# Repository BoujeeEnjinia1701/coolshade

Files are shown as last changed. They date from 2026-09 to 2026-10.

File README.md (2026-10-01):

# CoolShade

     

**Area:** Smart Cities · **TRL:** 3 of 9 (proof of concept on paper) · **Value-engineering target:** about $775 USD (hypothetical control target; estimated parts cost $882, $107 over) · **Difficulty:** 3 of 5

A solar-powered shade canopy with fine misting for bus stops, markets and queues, switching on only when heat stress is high.

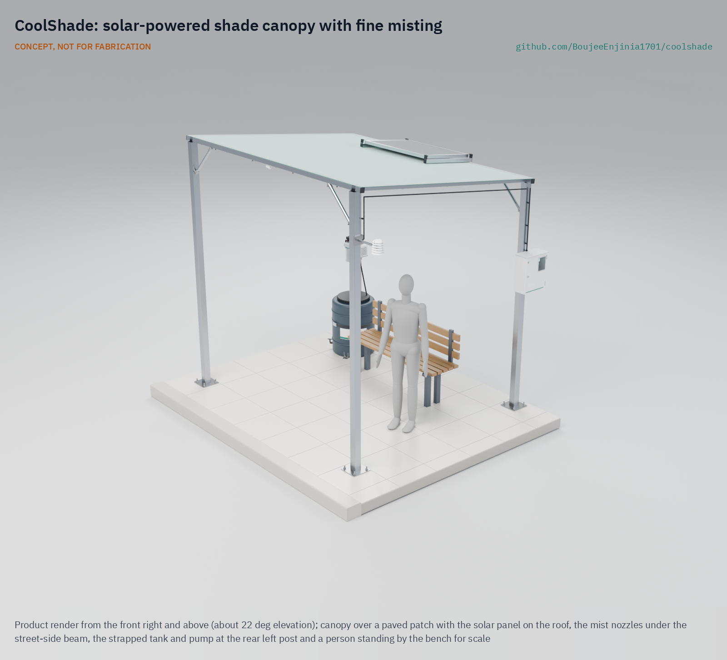
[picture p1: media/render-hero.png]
CoolShade: solar-powered shade canopy with fine misting, product render


[Prototype build plan](docs/05-build-plan.md) · [Design decisions](docs/06-design-decisions.md) · [Exploded render](media/render-exploded.png) · [Detail render](media/render-detail.png) · [Interactive 3D model](media/viewer.html) · [Concept blueprint (PDF)](media/concept-blueprint.pdf) · [General arrangement (PDF)](cad/drawings/CSH-DWG-001.pdf) · [Sizing calculations](docs/04-calcs/01-sizing.md) · [Review note](docs/REVIEW.md)

## Concept rationale

For a person waiting in the sun, radiant heat from the sun and hot pavement matters as much as air temperature, and shade removes most of it: in Tempe, Arizona, even shade sails cut the daytime mean radiant temperature by about 17 °C ([Middel et al., 2021](https://journals.ametsoc.org/view/journals/bams/102/9/BAMS-D-20-0193.1.xml)). CoolShade therefore starts with shade and adds low-pressure misting only when it helps: when the air is hot and dry enough for evaporation to cool it and someone is actually waiting. Gating on humidity and presence keeps water and energy use low (85 L and about 204 Wh on a hot, dry day, from the TRL 3 calculations) and avoids wetting people in humid air.

It is open and garage-buildable because the places that need it most, curbside stops, informal markets and distribution queues, rarely have power, budgets or staff for commercial misting systems. The frame is bolted steel tube, the roof is shade cloth, and the power and water parts are generic 12 V solar, pump and irrigation parts. Cities, schools and community groups can build, move, repair and audit it, including the water hygiene plan that any public misting system needs.

## Burning platform

WHO estimates about 489,000 heat-related deaths each year between 2000 and 2019, 45 % of them in Asia and 36 % in Europe, and notes that informal settlements are often hotter than other urban areas ([WHO](https://www.who.int/news-room/fact-sheets/detail/climate-change-heat-and-health)). In one summer, 2022, an estimated 61,672 people died of heat across 35 European countries ([Ballester et al., *Nature Medicine*, 2023](https://www.nature.com/articles/s41591-023-02419-z)).

Heat also takes work time from people who spend their day outdoors: the ILO projects that 2.2 % of total working hours worldwide will be lost to higher temperatures by 2030, equivalent to 80 million full-time jobs ([ILO, 2019](https://www.ilo.org/global/about-the-ilo/newsroom/news/WCMS_711917/lang--en/index.htm)). Cooling centers help people who can reach them, but many people are exposed where they must wait: at bus stops, in market lanes and in queues.

## Where it could be used

### By industry

| Industry | Use |
| --- | --- |
| Public transit | Shade and misting at busy unsheltered bus and minibus stops, and at terminals with long waits |
| Municipal markets | Cooled waiting and trading spots in open-air and informal markets during the midday peak |
| Public health and humanitarian response | Relief at clinic, vaccination, food and water distribution queues and at camp service points |
| Education | Shade at school gates, playgrounds and pickup areas |
| Construction and outdoor work | Shaded, cooled rest points near sites, with water use logged |
| Events and tourism | Queues at venues, heritage sites and festivals in hot seasons |

### By country or region

| Country or region | Why it matters there |
| --- | --- |
| United States | In all but 6 of the 175 largest urbanized areas, the average person of color lives in a census tract with higher surface urban heat island intensity than non-Hispanic white residents ([Hsu et al., 2021](https://www.nature.com/articles/s41467-021-22799-5)); transit riders in these areas wait in the heat |
| Europe | About 61,672 heat-related deaths in summer 2022 across 35 countries ([Ballester et al., 2023](https://www.nature.com/articles/s41591-023-02419-z)); shade for waiting places in dense cities has to be added without new buildings |
| India | An assessment of 37 city, district and state heat action plans found that vulnerable groups are rarely identified or targeted ([CPR, 2023](https://cprindia.org/briefsreports/how-is-india-adapting-to-heatwaves-an-assessment-of-heat-action-plans-with-insights-for-transformative-climate-action/)); low-cost shade at markets and stops is a practical measure such plans can fund |
| Sub-Saharan Africa | Africa warmed by about 0.3 °C per decade over 1991 to 2022 ([WMO](https://wmo.int/news/media-centre/africa-suffers-disproportionately-from-climate-change)); open-air markets and minibus ranks are central to daily life and shade, power and piped water cannot be assumed there |
| North Africa and the Middle East | WMO reports warming has been most intense in North Africa, with extreme heat in 2022 ([WMO](https://wmo.int/news/media-centre/africa-suffers-disproportionately-from-climate-change)); dry air there suits evaporative misting well |

## What sparked the idea

The idea traces back to Expo '92 in Seville, where the midday summer heat would have made the open public spaces unlivable without the site's designed microclimate. Its designers combined three measures: shading to block the sun, cold surfaces of vegetation and water, and cold air made by micronizing water in the passage areas where visitors walked and queued ([Castro Medina et al., *Sustainability*, 2022](https://doi.org/10.3390/su142114173)). That system served a showcase site with mains power, piped water and staff on hand. CoolShade takes the same order, shade first and mist second, and asks whether it can fit in a bolted canopy that runs from a panel and a tank at an ordinary bus stop or market lane, with the humidity and presence gating and the hygiene routine that an unattended public site needs.

## Problem

People waiting outdoors in extreme heat have nowhere to cool down, and public cooling is rarely where they wait. Full problem statement: [docs/01-problem.md](docs/01-problem.md).

## Concept

A four-post bolted steel canopy, 3.0 x 2.4 m, on a 2.8 x 2.35 m post grid, with a knitted shade cloth roof laced over the frame, a 100 W solar panel and a 12.8 V LiFePO4 battery. A 12 V diaphragm pump sends filtered water from a 120 L tank at about 7 bar to eight anti-drip nozzles under the roof beams. The controller mists only when the air is 32 °C or more, relative humidity is 60 % or less and a passive infrared sensor sees someone waiting; a normally open valve drains the line after every session. No camera or microphone is fitted.

TRL 3 calculations ([CSH-CAL-001](docs/04-calcs/01-sizing.md)): about 17 °C lower mean radiant temperature from the shade (from published shade sail measurements), 2.71 °C lower air temperature while spraying at 1 m/s wind (1.35 °C averaged over the spray cycle), 85 L of water and 204 Wh per hot, dry day, a 25 Ah battery lasting 1.26 days without sun, one tank lasting 1.41 days, headroom of 2,223 mm, and an estimated $882 in parts, $107 over the $775 value-engineering target (a hypothetical control target, not a limit) once every part needed to build it is counted. The frame and anchors are sized to survive a 30 m/s gust with the fabric removed; the fabric goes on only when forecast gusts are below 15 m/s (54 km/h), because its edge pull would overload the roof beams in a storm. Cost (R13) is over the value-engineering target by $107; savings worth trying are in the design decisions register. At risk: *Legionella* control in warm stored water and nozzle scaling; wetting cannot be judged until droplet data are in hand. Design decisions: [CSH-DDR-001](docs/decisions/0001-trl2-review-decisions.md), [CSH-DDR-002](docs/decisions/0002-recommendations-accepted.md) and [CSH-DDR-003](docs/decisions/0003-design-for-construction.md) (design for construction), indexed in the [design decisions register](docs/06-design-decisions.md).

Full design precis: [docs/02-concept.md](docs/02-concept.md). Requirements: [docs/03-requirements.md](docs/03-requirements.md).

## Key components

1. Posts, 80 x 80 mm galvanized steel, with knee braces
2. Roof frame, 50 x 50 mm steel, joined by angle cleats and rivet nuts
3. Shade fabric, knitted HDPE
4. Base plates, base cleats and anchors
5. Solar panel, 100 W, on rails at the roof's rear edge
6. LiFePO4 battery, 12.8 V 25 Ah
7. MPPT charge controller
8. Controller in a lockable IP65 enclosure
9. Sensor head: temperature and humidity in a radiation shield, PIR presence sensor
10. Misting pump, 12 V, about 7 bar, on an equipment plate
11. Filter, 5 µm, and check valve
12. Mist line loop with 8 anti-drip nozzles
13. Water tank, 120 L, opaque, strapped, with a low-level switch
14. Normally open drain valve and vacuum breaker
15. Hose and wiring harness

The priced bill of materials is in [bom/bom.csv](bom/bom.csv). The parametric model is [cad/src/model.py](cad/src/model.py), with STEP and STL exports in `cad/step/` and `cad/stl/`; `python cad/src/model.py --check` runs its constructability checks.

## Building the prototype

The prototype build plan ([docs/05-build-plan.md](docs/05-build-plan.md), CSH-BLD-001) shows, in pictures drawn from the model, how to make each of the canopy's steel parts and how to put the whole prototype together in 17 steps. Every joint is bolted: angle cleats join the tubes, bolts into the closed beams go into rivet nuts, and there is no welding. Making the design buildable changed some of the concept (posts moved out to carry the cloth's edges, the panel moved to the rear edge on its own bearer, and more); the changes are in [CSH-DDR-003](docs/decisions/0003-design-for-construction.md), and decisions still open are in the [design decisions register](docs/06-design-decisions.md). It is a plan, not yet built.

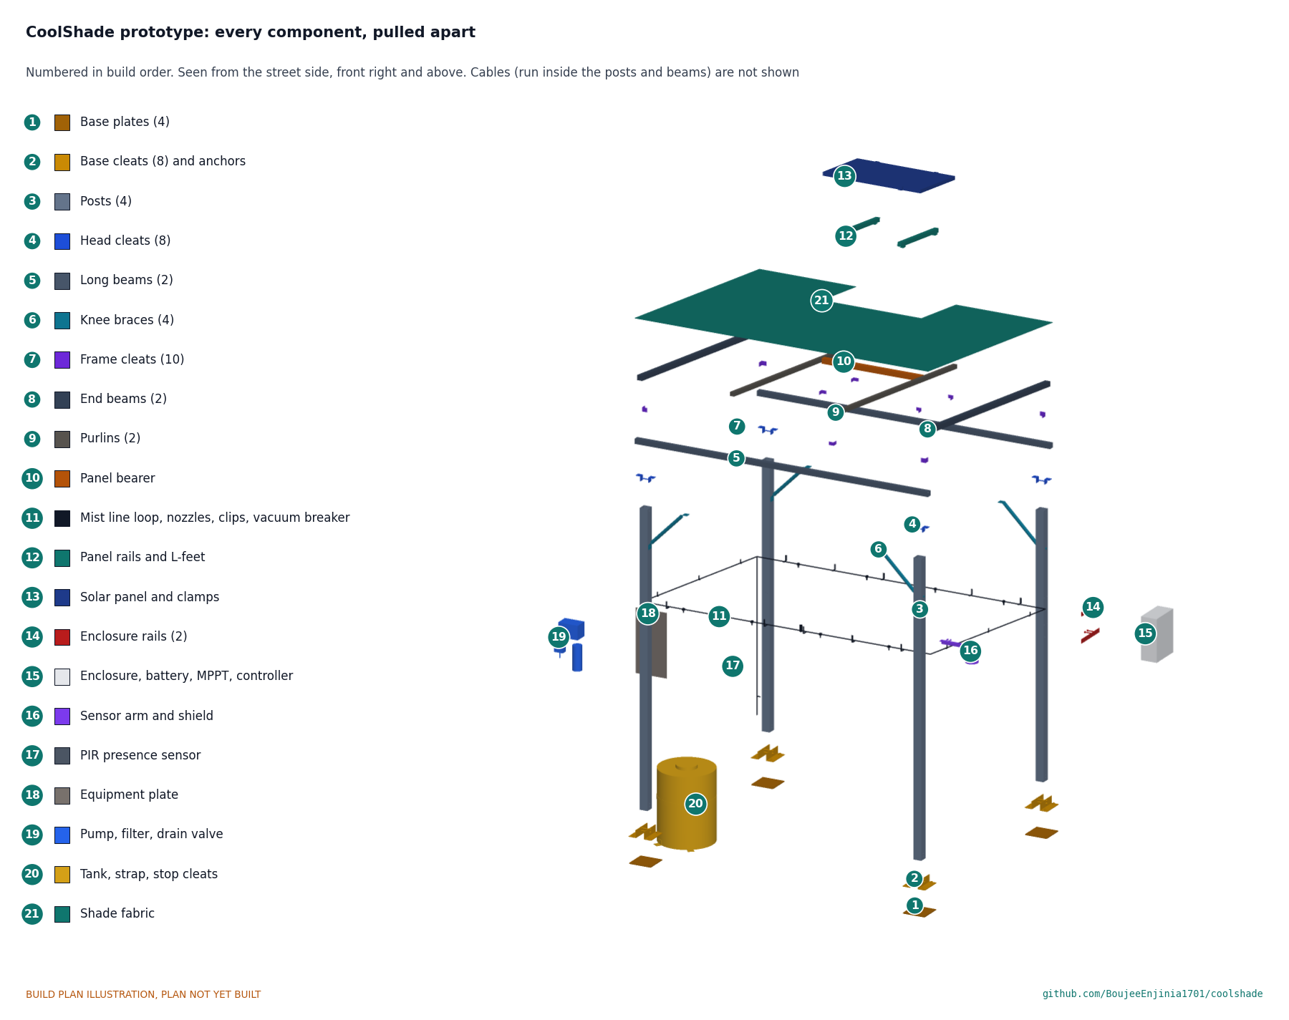
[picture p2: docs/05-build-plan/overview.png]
CoolShade prototype: every component, pulled apart and numbered in build order


## Safety

> Misting makes an aerosol. *Legionella* grows in water at 20 to 50 °C and infects people who breathe in contaminated mist ([WHO](https://www.who.int/news-room/fact-sheets/detail/legionellosis)). Use potable water only, keep the tank opaque and shaded, drain the line after every session, flush the tank daily and disinfect it weekly, and stop misting if the water is not maintained. Misting is ineffective in high humidity; the controller must switch off then.
>
> Lithium cells can overheat, vent and burn. Use protected cells or LiFePO4, fuse every pack, charge only within the cell maker's limits and never leave a first build charging unattended.
>
> The canopy is a wind-loaded structure: anchor it to a checked slab or footing, strap the tank, fit the fabric only when forecast gusts are below 15 m/s, and remove it before storms. Building it is work at height with heavy steel. The pump line runs at about 7 bar; depressurize it before opening fittings. Install on public land only with the asset owner's permission.

## Repository layout

| Folder | Contents |
| --- | --- |
| `docs/` | Problem, concept, requirements, calculations and design decisions |
| `cad/src/` | build123d Python source, the source of truth for all geometry |
| `cad/step/`, `cad/stl/` | Exported models for FreeCAD, other CAD tools and printing |
| `cad/drawings/` | 2D sketches and dimensioned drawings |
| `bom/` | Bill of materials |
| `electronics/` | KiCad schematics and PCB layouts |
| `firmware/` | Microcontroller code |
| `media/` | Renders, perspectives and photos |
| `build-log/` | Dated prototyping notes |

## Documentation

Controlled documents follow the portfolio [documentation standard](.kit/STANDARDS.md). Each carries a document ID (CSH-PRC-001 for the precis), a version and a revision history. Branded PDFs are built with `python .kit/render.py` and attached to GitHub Releases when a document is tagged, for example `CSH-PRC-001/v1.0`.

## Credits

Designed by Amish Chadha. See [CONTRIBUTORS.md](CONTRIBUTORS.md) for roles. To cite this design, use [CITATION.cff](CITATION.cff) (GitHub shows it as "Cite this repository").

AI assistance (Claude) was used to accelerate concept renders, prototype documentation and first-pass sizing calculations. Design direction and all decisions are Amish Chadha's, recorded in this repository's decision records (`docs/decisions/`).

## Licenses

- **Hardware** (CAD, drawings, BOM, electronics): [CERN-OHL-S v2](LICENSE)
- **Software** (firmware, scripts, notebooks): [MIT](LICENSE-SOFTWARE)

A project of the [Design Molecule](https://designmolecule.com) lab.

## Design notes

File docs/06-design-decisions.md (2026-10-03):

---
doc_id: CSH-DEC-001
title: CoolShade design decisions register
project: CoolShade
doc_type: Design decisions register
version: "0.5"
status: Draft
date: '2026-10-02'
author: Amish Chadha
license: CERN-OHL-S-2.0
revisions:
  - version: "0.1"
    date: '2026-09-30'
    author: Amish Chadha
    change: Register opened with the open decisions from the decision records, the review note and the build plan work
  - version: "0.2"
    date: '2026-10-01'
    author: Amish Chadha
    change: Budget treated as a value-engineering target
  - version: "0.3"
    date: '2026-10-02'
    author: Amish Chadha
    change: "Amish approved the recommendations for both open decisions; moved to decisions made; To confirm item 10 updated for the market lane"
  - version: "0.4"
    date: '2026-10-02'
    author: Amish Chadha
    change: "Design for construction (CSH-DDR-003, P1 to P16) accepted by Amish on 2026-10-02; moved from open for review to decisions made"
  - version: "0.5"
    date: '2026-10-02'
    author: Amish Chadha
    change: "To confirm item 11 carries the market lane: health authority and responsible person named by role"
---

# CoolShade design decisions register

Every design decision still to be made, and every decision made, in one place. Each decision is argued in full in its decision record under `docs/decisions/`; this register is the index Amish works from. The build plan (`docs/05-build-plan.md`, CSH-BLD-001) describes the design as it stands and does not list open decisions.

## Open decisions

None. All open decisions were decided on 2026-10-02.

## To confirm when parts are bought

*Table 1. Items to check against the real parts and site before or while buying.*

| # | What to confirm | Why it matters | Source |
| --- | --- | --- | --- |
| 1 | Nozzle flow (4 L/h each assumed) and droplet spectrum (Dv0.9 below about 80 µm) at 7 bar, from the nozzle maker | Water use (R7) and wetting (R5) depend on them | CSH-CAL-001 [C1], [D3] |
| 2 | The anchor type, its design resistance and the slab at the site: about 2.8 kN factored per anchor with the fabric off at 30 m/s | The anchors and slab hold the canopy down | CSH-CAL-001 [G13] |
| 3 | Steel quotes for lines 1, 2 and 4 (about 167 kg, priced at about $1.61/kg) | The cost (R13) may rise | CSH-CAL-001 [J2] |
| 4 | The M8 steel rivet nut's pull-out rating in a 2 mm wall is well above 0.16 kN, and its hole size (11 mm assumed; 7 mm for M5) | Rivet nuts hold the beams to the posts, braces, cleats and L-feet | CSH-DDR-003, P16; CSH-CAL-001 [G15] |
| 5 | The enclosure has moulded mounting holes outside its gasket and internal bosses for a gear plate | The enclosure screws to its rails from inside and stays sealed | CSH-DDR-003, P8 |
| 6 | The pump may be mounted on a vertical plate, and its foot pattern and port positions | The pump, the tee from the down pipe and the hoses are placed on the equipment plate from it | CSH-DDR-003, P11 |
| 7 | The solar mounting kit's L-feet reach the rails 15 mm above the tubes on the 7° slope, and the end clamps suit a 35 mm panel frame | The panel rails stand on L-feet on the bearer and the rear beam | CSH-DDR-003, P7 |
| 8 | The shade cloth maker can make the 1,020 x 670 mm notch with a reinforced hem and eyelets | The cloth comes off without touching the panel | CSH-DDR-003, P7 |
| 9 | The radiation shield has a top plate that takes one M8 bolt (or an adapter plate is made) | The shield hangs under the sensor arm | CSH-DDR-003, P9 |
| 10 | The street-side posts stand 25 mm inside the roof's street edge; check the setback from vehicles, stalls and walkways and the sight lines at the first site (a market lane, decided 2026-10-02) | The posts moved out 125 mm each side to carry the cloth's edges | CSH-DDR-003, P1 |
| 11 | A water hygiene plan for a market lane, acceptable to the environmental health authority of the city or county where the first site stands (named once the site is chosen; the Phoenix area is the first candidate), with the market operator's manager named as the person responsible for the daily drain and refill, the weekly disinfection and the sampling | *Legionella* control (R9) is at risk; no public trial without it | CSH-CAL-001 [I3]; CSH-PRC-001 |
| 12 | Water hardness at the site and a descaling method and interval for the 0.4 mm nozzles | Scaling (R16) is at risk | CSH-REQ-001 R16 |
| 13 | Fabric porosity and stretch, which set the fabric's edge pull | The 15 m/s fabric-on limit is set on the conservative solid-fabric case | CSH-CAL-001 [G7], [G8] |

## Value engineering

Value-engineering target: USD 775 (a hypothetical control target, not a limit). Estimated cost of the constructable design: USD 882 (USD 107, or 13.8 %, over the target). The concept came to USD 773, USD 2 under the target; the parts added to make it buildable add USD 109.

- **Main cost drivers:** the steel lines (1, 2 and 4), USD 269 for about 167 kg (about USD 1.61 per kg including cutting, drilling and galvanizing); the parts added for construction (cleats, rivet nuts, panel bearer and mounting kit, base cleats, equipment plate, enclosure rails, sensor arm, line clips, tank level switch, I2C extender, cloth notch and more fixings)(see `bom/bom.csv`).
- **Savings worth trying:** leave out the base plates (the cleats anchor straight to the slab) and make the panel rails from steel angle, which saves about USD 40; and get steel quotes, since the steel prices look low for small quantities and the real cost may be higher.

## Decisions made

*Table 2. Decisions made, newest last.*

| Date | Decision | Decided by | Record |
| --- | --- | --- | --- |
| 2026-09-25 | TRL 2 review items D1 to D7: low-pressure 7 bar misting; fixed thresholds (32 °C or more, 60 % RH or less, presence in the last 2 min, tank above its low level); no fans; tank as standard with mains optional; 3.0 x 2.4 m bolted four-post canopy on an existing slab; removable fabric before storms; no status link | Amish: "i accept all your recommendations, go with them across all repos." | CSH-DDR-001, CSH-DDR-002 |
| 2026-09-25 | Budget $775 (was $700) | Amish, same instruction | CSH-DDR-002, O1 |
| 2026-09-25 | R10 restated: frame and anchors survive 30 m/s with the fabric removed; fabric fitted only in forecast gusts below 15 m/s (54 km/h) | Amish, same instruction | CSH-DDR-002, N1 |
| 2026-09-25 | Load-release cord lacing to be studied at TRL 4 (on hold with TRL 4) | Amish, same instruction | CSH-DDR-002, N1c |
| 2026-09-25 | R4 restated as 2 °C while spraying; no fans | Amish, same instruction | CSH-DDR-002, N2 |
| 2026-09-25 | 25 Ah battery in place of 20 Ah; keep the fail-safe normally open drain valve | Amish, same instruction | CSH-DDR-002, N3 |
| 2026-09-30 | Design for construction: posts on a 2,800 x 2,350 mm grid with the long beams on their tops, angle cleats and rivet nuts at every roof joint, bolted post bases, flattened-end knee braces, panel at the rear edge on a bearer and L-feet with a notch in the cloth, equipment plate, enclosure rails, angle sensor arm, tank stop cleats, tank level switch and other changes (P1 to P16) | Made under Amish's 2026-09-30 instruction to make the design physically buildable ("If you are realising that the design cannot be built as per concept - fix the design assumptions to match and be physically feasible as you draw the illustrations."); the changes themselves were accepted on 2026-10-02 (below) | CSH-DDR-003 |
| 2026-10-02 | R14's tool list gains a hand rivet nut tool and a bench vice (option a); the rivet nuts are kept (open item 1) | Amish: "i approve your recommendations for all 555 open decisions." | CSH-DDR-003, A2 |
| 2026-10-02 | Design for construction accepted: the changes P1 to P16 and their knock-on changes, as made | Amish: "APPROVED: Design-for-construction changes in 10 repos (CityTwin, CoolShade, PalletPilot, Heliolite, PotholeLog, EarthPress, ReadyKit, CellCheck, CargoMule and ThermaCart)" | [CSH-DDR-003](decisions/0003-design-for-construction.md), Tables 1 and 2 |
| 2026-10-02 | First site type a market lane, with the market operator as co-design partner, in a hot, dry city; first candidate to approach a farmers' market operator in the Phoenix area, with Arizona State University's urban heat researchers as the candidate measurement partner (open item 2) | Amish: "i approve your recommendations for all 555 open decisions." | CSH-DDR-001, O2; CSH-DDR-002 |

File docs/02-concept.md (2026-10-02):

---
doc_id: CSH-PRC-001
title: CoolShade design precis
project: CoolShade
doc_type: Design precis
version: "0.7"
status: Draft
date: '2026-10-02'
author: Amish Chadha
license: CERN-OHL-S-2.0
revisions:
- version: "0.1"
  date: '2026-09-25'
  author: Amish Chadha
  change: Initial scaffold
- version: "0.2"
  date: '2026-09-25'
  author: Amish Chadha
  change: Populate to TRL 2 (architecture, components, first-order numbers, safety, media)
- version: "0.3"
  date: '2026-09-25'
  author: Amish Chadha
  change: TRL 3 update from CSH-CAL-001 and CSH-DDR-001 (numbers checked, shorter knee braces, vacuum breaker, closed mist line loop, tank strap, design choices adopted for TRL 3, GA drawing CSH-DWG-001)
- version: "0.4"
  date: '2026-09-25'
  author: Amish Chadha
  change: Recommendations accepted by Amish (DDR-002)
- version: "0.5"
  date: '2026-09-30'
  author: Amish Chadha
  change: Constructable design (CSH-DDR-003) and build plan CSH-BLD-001; posts on a 2.8 x 2.35 m grid, panel at the rear edge, cleats and rivet nuts, cost $882 (R13 not met, new budget proposed)
- version: "0.6"
  date: '2026-10-01'
  author: Amish Chadha
  change: Budget treated as a value-engineering target
- version: "0.7"
  date: '2026-10-02'
  author: Amish Chadha
  change: "First site type and partner decided by Amish on 2026-10-02; first candidates named"
---

# CoolShade design precis

## Summary

CoolShade is a bolted steel shade canopy, 3.0 x 2.4 m in plan, with a knitted shade cloth roof, a 100 W solar panel, a 12 V battery and a low-pressure misting line. It gives shade all day and mists only when the air is hot and dry enough for misting to help and a person is waiting. The TRL 3 calculations (CSH-CAL-001) give, for a hot, dry design day (38 °C, 25 % relative humidity), 85 L of water and 203.8 Wh of electricity per day, an air temperature drop of 2.71 °C while spraying at 1 m/s wind (1.35 °C averaged over the cycle) and, from published shade sail data, a drop in mean radiant temperature of about 17 °C, which is where most of the relief comes from. On 2026-09-25 Amish accepted the recommendations (CSH-DDR-001 and CSH-DDR-002): R4 is now judged while spraying, R10 with the fabric removed above 15 m/s gusts, the battery is 25 Ah and the value-engineering target is $775. On 2026-09-30 the design was made constructable (CSH-DDR-003): every part is now modelled as it is made or bought and every joint as it is bolted, and the prototype build plan CSH-BLD-001 shows how to build it. The parts added for that bring the estimated cost to $882 against the $775 value-engineering target (a hypothetical control target), so R13 is over the target by $107 (savings worth trying are in CSH-DEC-001); water hygiene (R9) and nozzle scaling (R16) are at risk, and wetting (R5) needs droplet data.

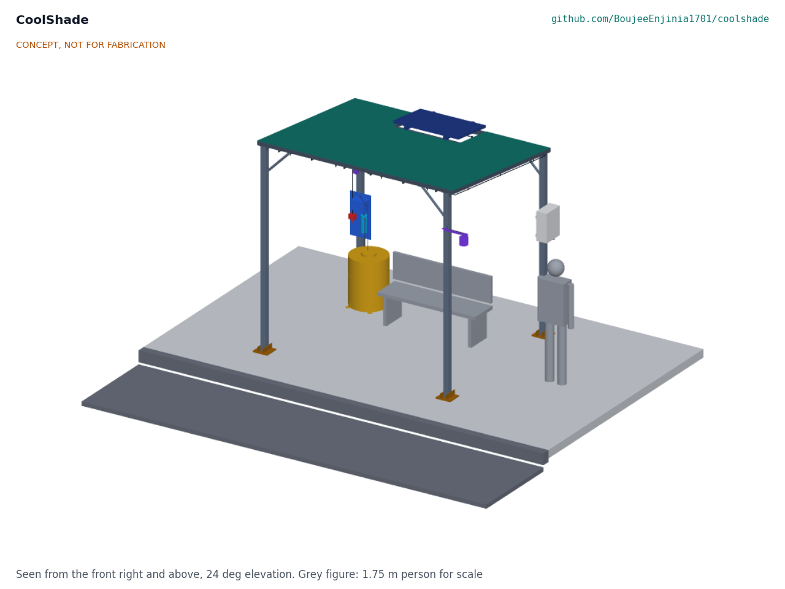
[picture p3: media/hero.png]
Hero render


*Figure 1. CoolShade at a curbside stop next to an existing bench, with a 1.75 m person for scale. Kit parts are colored; the street and bench are grey.*

## How it works

1. **Shade.** Four 80 mm square steel posts on a 2.8 x 2.35 m grid carry two horizontal long beams at the roof's street and rear edges; sloping end beams and purlins between them make a mono-pitch roof frame (7.1°, high edge at the street), with knitted HDPE shade cloth laced over it. The cloth blocks most direct sun while letting hot air escape.
2. **Harvest and store.** A 100 W panel on rails at the rear edge of the roof, in a notch in the cloth, charges a 12.8 V, 25 Ah LiFePO4 battery through an MPPT controller. Everything runs at 12 V DC.
3. **Sense.** A temperature and humidity sensor in a radiation shield on an arm off the front post measures the ambient air outside the mist zone. A passive infrared sensor under the front beam detects whether anyone is waiting. No camera or microphone is fitted.
4. **Decide.** The controller mists only when air temperature is 32 °C or more, relative humidity is 60 % or less, someone has been detected in the last 2 min, and the tank is above its low level (thresholds decided by Amish, CSH-DDR-001 D2). A 10 s control loop with a 20 s debounce stops the spray within 30 s of a condition failing. In humid air it does not mist, because misting would add little cooling and wet people.
5. **Mist.** A 12 V diaphragm pump draws from a 120 L opaque tank through a 5 µm filter and pushes water at about 7 bar through a closed loop of mist line just inboard of the long beams and under the end beams to eight anti-drip nozzles along the front and rear runs, in cycles of 20 s on and 20 s off. Fine droplets evaporate and cool the air under the canopy.
6. **Drain.** When the pump stops at the end of a session, a normally open drain valve at the low point empties the line in about 30 s, while a vacuum breaker at the front, highest point of the loop lets air in past the anti-drip nozzles. On design days the tank is drained of its residual and refilled with about 95 L daily, so no water is more than 24 h old, and it is disinfected weekly.

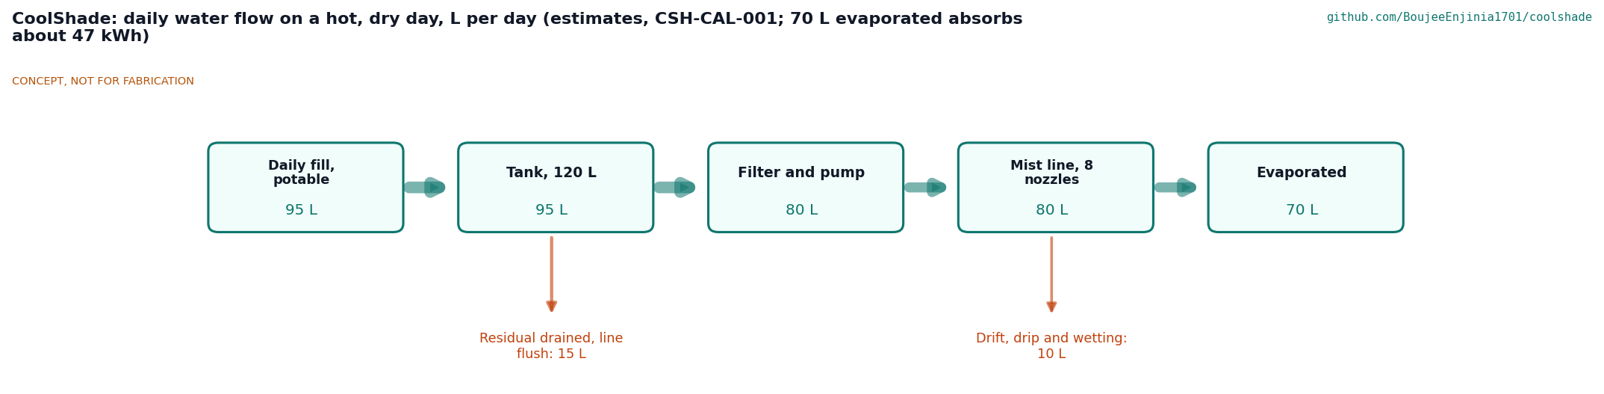
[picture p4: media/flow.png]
Water flow


*Figure 2. Daily water flow on the design day, in liters. All values are estimates.*

## Main components

Numbers match the exploded view (Figure 3) and `bom/bom.csv`.

Table 1. Main components.

| # | Component | Choice | Notes |
| --- | --- | --- | --- |
| 1 | Posts with knee braces | 80 x 80 x 3 mm galvanized SHS, 2.61 and 2.90 m, on a 2.8 x 2.35 m grid; one 32 mm tube brace each with flattened, bolted ends, bends 350 mm down and 350 mm along the beam | Utilization 0.30 in a 30 m/s gust (CSH-CAL-001) |
| 2 | Roof frame | 50 x 50 mm SHS long beams on the post tops, end beams and a panel bearer; two 40 x 40 mm purlins; angle cleats with M8 bolts into rivet nuts | About 7° mono-pitch; no welding |
| 3 | Shade fabric | Knitted HDPE, about 90 % UV block, 3.0 x 2.4 m with a notch under the panel, laced over the frame | Fitted only in forecast gusts below 15 m/s (CSH-DDR-001, D6; CSH-DDR-002) |
| 4 | Base plates and anchors | 220 x 220 x 10 mm plates and two 75 x 75 mm angle cleats per post, four M16 anchors each, into an existing slab | Footing checked per site |
| 5 | Solar panel | 100 W monocrystalline on two rails and four L-feet, at the roof's rear edge | About 1,000 x 670 mm |
| 6 | Battery | 12.8 V, 25 Ah LiFePO4 with BMS and cold-charge cutoff | Inside item 8, fused; 25 Ah for energy margin (CSH-DDR-002) |
| 7 | MPPT charge controller | 12 V, 10 A, LiFePO4 profile | Inside item 8 |
| 8 | Controller and enclosure | Lockable IP65 box on two rails on the rear right post, about 1.44 to 1.86 m high; microcontroller, pump and valve drivers, fuses | Firmware not started (TRL 4) |
| 9 | Sensor head | SHT4x-class temperature and humidity sensor in a multi-plate shield on an angle arm at 2.4 m, plus a PIR presence sensor | No camera or microphone |
| 10 | Misting pump | 12 V diaphragm pump, about 7 bar, about 60 W, pressure switch | On an equipment plate on the rear left post, with items 11 and 14 |
| 11 | Filter and check valve | 5 µm cartridge, inlet strainer | Protects 0.4 mm nozzles |
| 12 | Mist line and nozzles | About 12 m of 9.5 mm (3/8 in) line as a closed loop on hanger clips, 8 brass anti-drip nozzles, about 0.4 mm | 32 L/h while spraying at 4 L/h per nozzle (to confirm) |
| 13 | Water tank | 120 L, opaque, food-grade, lockable, with a low-level switch; strapped to the rear left post, with two stop cleats | Optional mains float valve with backflow preventer; strap because an empty tank tips in a 30 m/s gust |
| 14 | Drain valve and vacuum breaker | 12 V normally open solenoid at the low point; air admittance valve at the loop's high point | Empties the line in about 30 s after every session |
| 15 | Hose and wiring harness | Suction and delivery hose, outdoor cable, glands | |

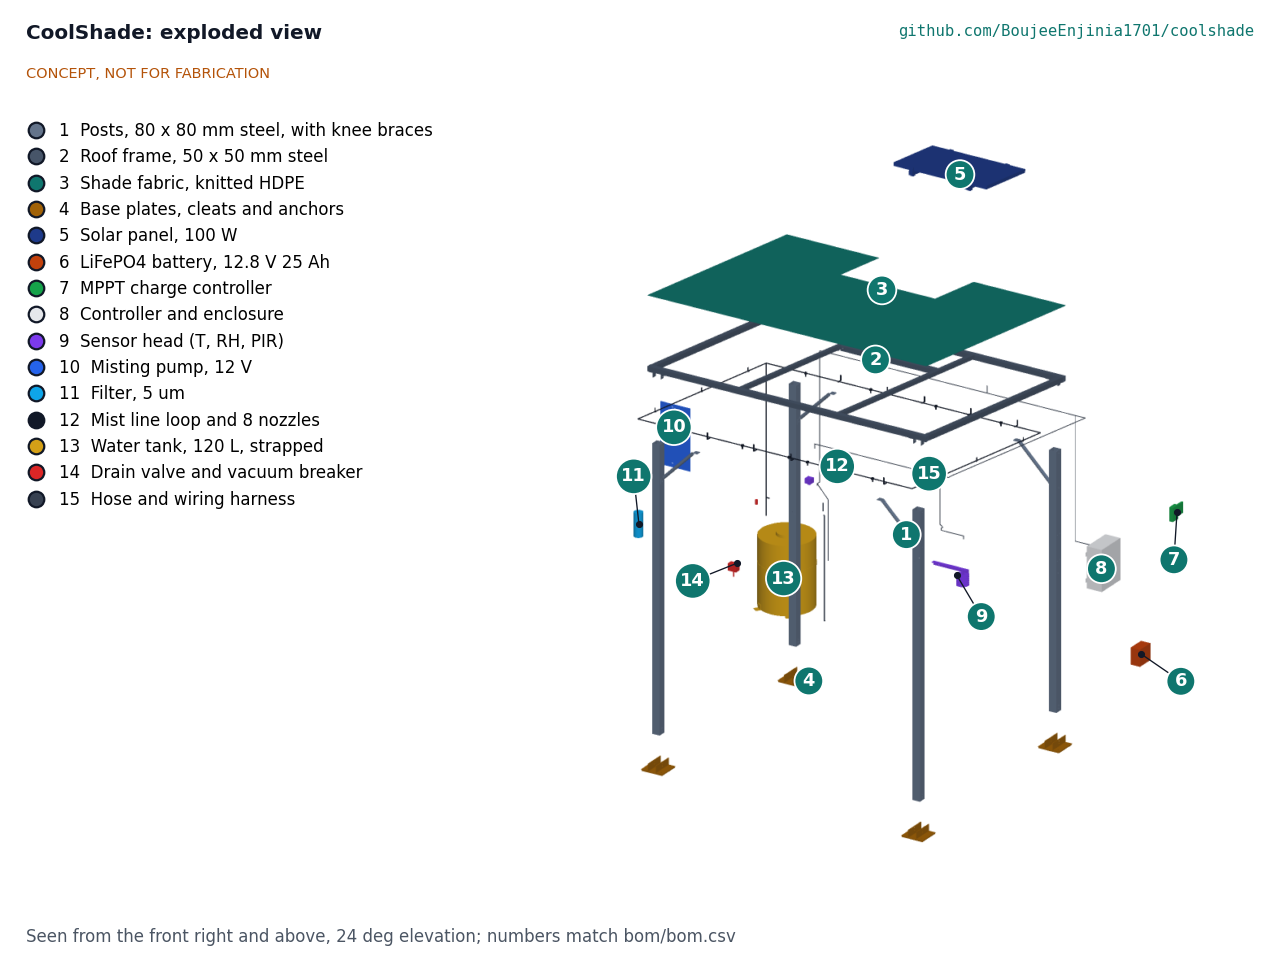
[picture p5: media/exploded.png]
Exploded view


*Figure 3. Exploded view with numbered callouts matching the BOM. Items 6 and 7 are shown out of the enclosure (item 8) that houses them.*

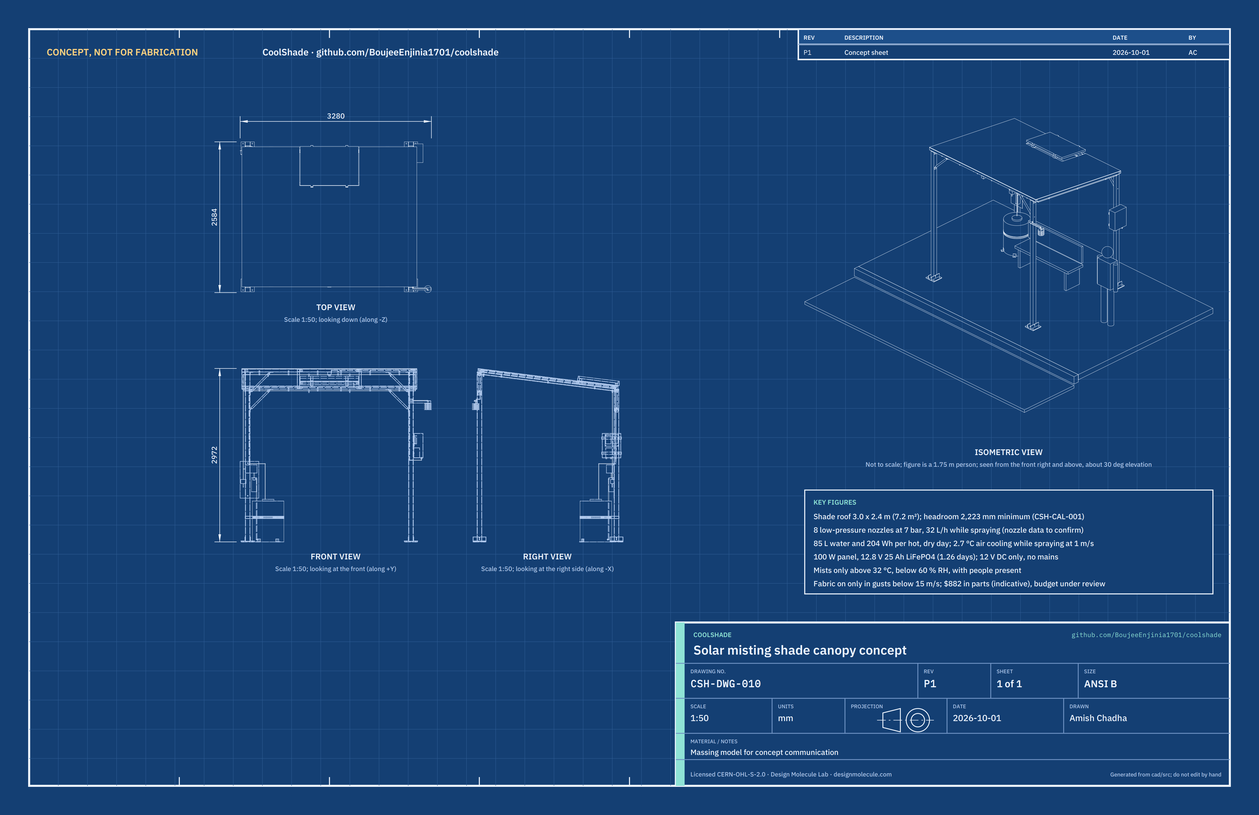
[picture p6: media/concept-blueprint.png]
Concept blueprint


*Figure 4. Concept sheet CSH-DWG-010 with orthographic and isometric views and key figures.*

The general arrangement drawing CSH-DWG-001 (Rev P4, `cad/drawings/CSH-DWG-001.pdf`) gives the main dimensions and interfaces from the parametric model `cad/src/model.py`. It is preliminary and not for fabrication.

No cutaway is provided: the canopy is open, and the only enclosed parts (items 6 to 8) are shown in the exploded view.

## Numbers checked at TRL 3

All values come from CSH-CAL-001 and its script `docs/04-calcs/sizing.py`; the tags in brackets are lines of its output. They are first-principles estimates, not measurements.

### Water and misting

Assumptions: eight nozzles at 4 L/h each at 7 bar (to be checked against nozzle datasheets; this implies a discharge coefficient of 0.24 for a 0.4 mm orifice), 20 s on and 20 s off while active (50 % duty), 5 h of active misting on the design day, 87 % of sprayed water evaporating in the air, and a daily flush of 5 L.

Table 2. Water use on the design day.

| Quantity | Value | Basis |
| --- | --- | --- |
| Flow while spraying | 32 L/h | 8 x 4 L/h [C2] |
| Average flow while active | 16 L/h | 50 % duty |
| Sprayed per day | 80 L | 16 L/h x 5 h |
| Used per day, with flush | 85 L | 80 + 5 L |
| Drawn per day with the drain-and-refill routine | 95 L | Daily fill; about 10 L residual drained [C5] |
| Evaporated in the air | 69.6 L | 87 % of 80 L |
| Tank endurance | 1.41 design days | 120 L / 85 L [C4] |
| Mist line volume and drain time | 0.40 L, about 30 s | 11.91 m of 6.5 mm bore; 3 mm valve orifice [C7] |

R7 holds up to 4.75 L/h per nozzle [C3]. Whether the nozzles keep people dry (R5) depends on droplet size: droplets up to about 100 µm evaporate before reaching head height on the design day, but only up to about 80 µm in the most humid air the controller allows [D3]. No droplet data are in hand.

### Cooling

Assumptions: latent heat of evaporation 2.43 MJ/kg; air density 1.15 kg/m³ and specific heat 1,006 J/(kg K) at 35 °C; air crossing a control volume 3.0 m long and 2.0 m high at the wind speed; all evaporation within that volume.

Table 3. Cooling on the design day.

| Quantity | Value | Basis |
| --- | --- | --- |
| Heat absorbed by evaporation, averaged | 9.40 kW | 13.9 L/h evaporated x 2.43 MJ/kg [E1] |
| Heat absorbed while spraying | 18.8 kW | 27.8 L/h evaporated |
| Air through the zone at 1 m/s | 6.90 kg/s | 6 m² x 1 m/s x 1.15 kg/m³ |
| Air temperature drop at 1 m/s | 2.71 °C while spraying, 1.35 °C averaged | Q / (m x cp) [E2] |
| Wind speed for a 2 °C drop while spraying (R4 as restated) | 1.35 m/s or less | Same method [E3] |
| Wind speed for a 2 °C averaged drop (former R4) | 0.68 m/s or less | Same method [E3] |
| Air temperature drop at 0.3 m/s | 4.5 °C averaged | Wetting risk rises in still air [E3] |
| Wet-bulb temperature, 38 °C and 25 % RH | 23.0 °C | Stull approximation; far from the limit [E4] |
| Humidity added at 1 m/s | 0.56 g/kg | Small against about 10 g/kg ambient |
| Heat absorbed per day | 47 kWh | 69.6 L x 2.43 MJ/kg [E5] |
| Mean radiant temperature drop from shade | about 17 °C | Shade sails in Tempe ([Middel et al., 2021](https://journals.ametsoc.org/view/journals/bams/102/9/BAMS-D-20-0193.1.xml)) |

The shade does most of the work: a 17 °C drop in mean radiant temperature matters more to a person standing in the sun than a 1 to 3 °C drop in air temperature. Misting adds a noticeable but smaller benefit, and only in dry air. This is why the controller must never mist in humid air. R4 is judged while spraying (CSH-DDR-002), where the 2.71 °C drop at 1 m/s meets the 2 °C target; averaged over the cycle it would need calmer air. No fans are fitted (CSH-DDR-001, D3, confirmed in CSH-DDR-002), because the shade gives most of the relief and fans would need a larger battery.

### Energy

Table 4. Daily energy budget on the design day.

| Load or source | Value | Basis |
| --- | --- | --- |
| Pump | 150 Wh | 60 W x 50 % x 5 h [F1] |
| Controller and sensors | 28.8 Wh | 1.2 W x 24 h |
| Drain valve held closed while active | 25 Wh | 5 W x 5 h |
| **Total use** | **203.8 Wh** | |
| Panel harvest | 337.5 Wh | 100 W x 4.5 h x 0.75 [F2] |
| Battery usable | 256.0 Wh | 12.8 V 25 Ah, 320 Wh x 80 %; 1.256 design days |

The panel covers the design day 1.66 times, and the 25 Ah battery covers 1.256 design days without sun, so R8 is met (the former 20 Ah battery gave 1.005 days, with 1 Wh to spare). A latching drain valve would save 24.5 Wh, but it would not open by itself if power failed, so the normally open valve is kept [F3]. The enclosure runs about 3.6 K above the air, so the battery stops charging (at 45 °C) when the air is above about 41.4 °C [F5].

### Structure and wind

Assumptions: 30 m/s gust, air density 1.2 kg/m³, net normal force coefficient 1.2 on the roof with the fabric treated as solid, center of pressure a quarter of the depth off center, S275 steel with a partial factor of 1.5 on wind, fabric sag 5 % of its span.

Table 5. Wind check.

| Quantity | Value | Basis |
| --- | --- | --- |
| Dynamic pressure | 540 Pa | 0.5 x 1.2 x 30² [G2] |
| Normal force on the roof | 4.67 kN | 540 Pa x 1.2 x 7.2 m² |
| Post base moment | 1.24 kN m | Horizontal roof load 1.21 kN plus post drag, cantilevers [G3] |
| Post stress, 80 x 80 x 3 SHS | 54 MPa, utilization 0.30 factored | Z = 22,861 mm³ [G4] |
| Long beam, roof pressure as a simple span | Utilization 0.70 | 50 x 50 x 2 SHS over 2.8 m [G6] |
| Long beam, fabric edge pull at 5 % sag | 3.89 kN/m, utilization 3.52 | Membrane tension p L² / (8 f) [G7] |
| Fabric-on gust limit for the beams | about 16 m/s (58 km/h) | Edge pull the beams can take, 1.11 kN/m [G8] |
| Anchor tension, factored, original fabric-on case | about 6.4 kN per M16 anchor | Uplift plus base moment [G10] |
| Restated R10, fabric off at 30 m/s | Posts 0.14, panel bearer 0.02, purlins 0.07; anchors about 2.8 kN | Panel as a flat plate [G13] |
| Restated R10, fabric on at 15 m/s | Long beams 0.88, posts 0.07; anchors about 1.5 kN | Same solid-fabric case [G14] |
| Ballast needed if not anchored | 309 kg | Uplift less dead load [G11] |

The posts are adequate. The weak point is the fabric: a tensioned cloth pulls its edges inward far harder than the pressure alone suggests, and on the conservative solid-fabric case it overloads the 50 mm long beams in a 30 m/s gust. Porosity and stretch would reduce the pull, but no data are in hand. R10 is therefore restated (CSH-DDR-002): the frame and anchors survive 30 m/s with the fabric removed, and the fabric is fitted only when forecast gusts are below 15 m/s (54 km/h), where the beams reach 0.88. The restated R10 is met on paper. Taking the fabric off before storms (CSH-DDR-001, D6) is structurally necessary. The anchors must be checked against the chosen anchor's data and the actual slab. The unit must be anchored; ballast alone is impractical. An empty tank would tip over in the same gust, so it is strapped to the rear left post [G12].

### Mass and cost

- Steel about 167 kg with its cleats and plates (a front post 21.0 kg, the heaviest part); panel about 7 kg; battery about 3 kg; full tank about 128 kg [G1, H1].
- Value-engineering target: $775 (`budget_usd`, a hypothetical control target, not a limit). Estimated cost of the constructable design: $882 (indicative, see `bom/bom.csv`), $107 over the target after the parts added to make the design buildable (CSH-DDR-003) [J1]. Savings worth trying are in CSH-DEC-001. The steel prices look low for small quantities [J2].

## Key design choices

Decided by Amish, 2026-09-25: go with recommendation (CSH-DDR-001, CSH-DDR-002).

1. Low-pressure (about 7 bar) 12 V misting rather than high-pressure (about 70 bar) mains misting, so the unit runs off-grid and stays low-voltage. The trade-off is larger droplets and a higher wetting risk.
2. Humidity and presence gating with fixed thresholds, so water and energy are used only when misting helps someone.
3. Tank supply with an optional mains connection, so it can go anywhere.
4. Drain-after-use, a vacuum breaker and a daily drain-and-refill as the main defenses against *Legionella*.
5. Knitted shade cloth rather than a solid roof: cheaper, lighter and lets hot air escape, but it does not keep rain off, and it must come off before storms.
6. Bolted, movable frame on existing slabs, so a city can trial it at a site and move it.
7. No fans and no status link in the first prototype.

## Integration with other lab projects

- **HeatMap Node** measures street-level heat stress and can show where a CoolShade would help most, and whether it did.
- **FieldNode** could provide an optional LoRaWAN status link (counts and levels only). Its 6 W panel is far too small to run the pump, so CoolShade keeps its own power system. No link is fitted in the first prototype (CSH-DDR-001, D7), so CoolShade places no interface demands on FieldNode.

## Safety

> **Safety:** Misting is an aerosol, and *Legionella* grows in water at 20 to 50 °C and infects people who inhale contaminated mist ([WHO](https://www.who.int/news-room/fact-sheets/detail/legionellosis)). Use potable water only; keep the tank opaque, shaded and locked; drain the line after every session; drain the tank's residual and refill it daily; disinfect weekly; and stop misting if the water is not maintained. A site owner must name a responsible person for water hygiene.
>
> **Safety:** The 12.8 V LiFePO4 battery can overheat and burn if shorted, damaged or charged outside its limits. Fuse it at the terminal, use a BMS with cold-charge cutoff, keep it in the ventilated, locked enclosure, and never install a damaged or wet battery.
>
> **Safety:** The pump line runs at about 7 bar. Depressurize before opening fittings, and wear eye protection when working on it.
>
> **Safety:** The canopy is a wind-loaded structure. Anchor it to a checked slab or footing, strap the tank, fit the fabric only when forecast gusts are below 15 m/s (54 km/h) and remove it before storms (on the conservative calculation the roof beams are overloaded with the fabric on above gusts of about 16 m/s), and inspect bolts and anchors regularly. Building it is work at height with heavy steel; use two people, stable ladders and gloves, and deburr all cut edges.
>
> **Safety:** Wet surfaces can be slippery. Set nozzles and duty cycle so people and the ground stay dry; stop misting and adjust if puddles form.
>
> **Safety:** CoolShade is shade and local cooling, not a medical intervention or a cooling center. People with heat illness need medical help.

## Open questions

Open decisions and items to confirm are kept in the design decisions register (`docs/06-design-decisions.md`, CSH-DEC-001); the list below is the concept's own.

- [ ] Nozzle flow and droplet spectrum at 7 bar from the maker's data (R5, R7).
- [ ] Fabric porosity and stretch under wind, which decide the fabric's edge pull; a load-release cord lacing (TRL 4, on hold).
- [ ] Water hygiene plan acceptable to the local health authority, including sampling (R9).
- [ ] Hard water scaling and a descaling method (R16).
- [ ] Site anchor details on different slabs; footing option where no slab exists.
- [ ] Steel quotes, since the $882 estimated parts cost is over the $775 value-engineering target (R13).
- [x] First site type and co-design partner: decided 2026-10-02, a market lane with the market operator as co-design partner; first candidate to approach a farmers' market operator in the Phoenix area, with Arizona State University's urban heat researchers as the candidate measurement partner (CSH-DEC-001).

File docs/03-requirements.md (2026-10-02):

---
doc_id: CSH-REQ-001
title: CoolShade requirements
project: CoolShade
doc_type: Requirements
version: "0.7"
status: Draft
date: '2026-10-02'
author: Amish Chadha
license: CERN-OHL-S-2.0
revisions:
- version: "0.1"
  date: '2026-09-25'
  author: Amish Chadha
  change: Initial scaffold
- version: "0.2"
  date: '2026-09-25'
  author: Amish Chadha
  change: First measurable requirements for TRL 2, with status against the concept
- version: "0.3"
  date: '2026-09-25'
  author: Amish Chadha
  change: TRL 3 status from CSH-CAL-001 for every requirement; R6 thresholds adopted under CSH-DDR-001; R13 stated against $700 and the proposed $750
- version: "0.4"
  date: '2026-09-25'
  author: Amish Chadha
  change: Recommendations accepted by Amish (DDR-002)
- version: "0.5"
  date: '2026-09-30'
  author: Amish Chadha
  change: Status from CSH-CAL-001 v0.3 for the constructable design (CSH-DDR-003); R13 not met against $775, new budget proposed
- version: "0.6"
  date: '2026-10-01'
  author: Amish Chadha
  change: Budget treated as a value-engineering target
- version: "0.7"
  date: '2026-10-02'
  author: Amish Chadha
  change: "R14 tool list adds a hand rivet nut tool and a bench vice, decided by Amish on 2026-10-02"
---

# CoolShade requirements

These are first-pass requirements for the concept. Targets are proposals for review, not yet validated with users, and will be revised after co-design sessions (see CSH-PRB-001). The status column comes from the TRL 3 calculations in CSH-CAL-001 v0.3, for the constructable design of CSH-DDR-003: one requirement is over its value-engineering target (R13 cost: the parts added to make the design buildable bring the estimate to $882 against the $775 target, $107 over), two are at risk (R9 water hygiene, R16 scaling), one cannot be judged at TRL 3 (R5 wetting, for lack of droplet data) and thirteen are met, four of them by design and R10 on paper. On 2026-09-25 Amish accepted the recommendations (CSH-DDR-002), which changed three targets: R4 is restated as 2 °C while spraying (was 2 °C averaged, not met at 1 m/s); R10 is restated as surviving 30 m/s with the fabric removed, with the fabric fitted only in forecast gusts below 15 m/s (was 30 m/s with the fabric fitted, not met); and the R13 value-engineering target is $775 (was $700). The R6 thresholds are decided by Amish (CSH-DDR-001, D2).

**Design day:** 38 °C air, 25 % relative humidity, clear sky, wind about 1 m/s, 5 h of misting demand, 4.5 peak sun hours. **Humid edge:** 32 °C and 60 % relative humidity, the wettest air in which the controller still mists.

Table 1. Requirements, targets and status after the TRL 3 calculations (CSH-CAL-001 v0.3; tags in brackets are lines of its script output).

| ID | Requirement | Target | Verification (TRL 3 or later) | Status (CSH-CAL-001) |
| --- | --- | --- | --- | --- |
| R1 | Shaded waiting area | 6 m² or more of shade at solar noon; room for at least 6 people standing or seated and one wheelchair space of 0.8 x 1.2 m | Plan layout; sun path check per site | Met: shadow 6.30 m² or more at any sun elevation of 45° or more; room for 8 standing, 3 seated and a wheelchair [A2, A3]. Where the shadow falls depends on the site |
| R2 | Headroom | Clear height 2.2 m or more under any part of the frame, nozzle or brace in the waiting area | Model check | Met: 2,223 mm under the flattened ends of the rear knee braces; nozzle tips 2,559 mm or higher [B2, B3] |
| R3 | Radiant heat reduction | Mean radiant temperature under the canopy at least 15 °C below full sun at midday on the design day | Literature comparison; later field measurement with a globe thermometer (HeatMap Node method) | Met on published evidence: about 17.3 °C for shade sails in Tempe ([Middel et al., 2021](https://journals.ametsoc.org/view/journals/bams/102/9/BAMS-D-20-0193.1.xml)); unverified for this fabric |
| R4 | Air cooling from misting | Air temperature in the waiting zone (0.5 to 2.0 m height) at least 2 °C below ambient while spraying on the design day (restated, CSH-DDR-002; was averaged over the spray cycle) | Energy balance at TRL 3; later field test | Met: 2.71 °C while spraying at 1 m/s, held to 1.35 m/s; 1.35 °C averaged over the cycle [E2, E3] |
| R5 | No wetting | No perceptible wetting of skin or clothing at 1.5 m height on the design day; no puddles on the waiting area | Droplet size data from nozzle maker; later field test | Not verifiable at TRL 3: met only if the nozzle's Dv0.9 is below about 80 µm at 7 bar; no droplet data yet [D3] |
| R6 | Smart activation | Mists only when air temperature is 32 °C or more, relative humidity is 60 % or less, presence is detected in the last 2 min and the tank is above its low level; stops within 60 s when any condition fails | Control logic review; later bench test | Met by design: stops within 30 s [I1]; thresholds decided (CSH-DDR-001, D2) |
| R7 | Water use | 100 L or less per design day | Nozzle flow calculation | Met: 85 L used, 95 L drawn with the drain-and-refill routine [C2, C5]; holds up to 4.75 L/h per nozzle [C3] |
| R8 | Energy autonomy | Energy-neutral on the design day from the onboard panel; battery covers one full design day with no sun | Energy budget | Met: 203.8 Wh used against 337.5 Wh harvested; 25 Ah battery (CSH-DDR-002; was 20 Ah, 1.005 days) covers 1.256 design days; no charging in air above about 41 °C [F2, F5] |
| R9 | Water hygiene | Potable-quality supply water; 5 µm filtration; mist line drained within 5 min after every session; water in the tank 48 h old or less; opaque, shaded, lockable tank; documented weekly disinfection | Design review; later microbiological sampling with a partner lab | **At risk:** line drains in about 30 s with the vacuum breaker and water stays under 24 h old with the routine [C5, C7], but tank water sits at about 34 °C, in the 20 to 50 °C *Legionella* growth range ([WHO](https://www.who.int/news-room/fact-sheets/detail/legionellosis)) [I3] |
| R10 | Wind resistance | Frame and anchors survive a 3 s gust of 30 m/s (108 km/h) with the fabric removed; fabric fitted only when forecast gusts are below 15 m/s (54 km/h); fabric removable in 15 min or less (restated, CSH-DDR-002; was 30 m/s with the fabric fitted) | Structural calculation at TRL 3 | Met on paper: fabric off at 30 m/s, posts 0.14, panel bearer 0.02 and purlins 0.07 utilization [G13]; fabric on at 15 m/s, long beams 0.88 [G14]; anchors need about 2.8 kN each, to be confirmed per site. The original case gives 3.52 on the beams [G7] |
| R11 | Privacy | No camera or microphone; presence by passive infrared only; if a status link is fitted, only counts and levels (on-time, water used, temperature, humidity, faults) leave the device | Design review | Met by design; no status link fitted (CSH-DDR-001, D7) |
| R12 | Electrical safety | 12 V DC only, no mains; battery fused at the terminal; all electronics in a lockable IP65 enclosure; LiFePO4 chemistry with BMS and cold-charge cutoff | Design review | Met by design: 15 A terminal fuse, margin 2.0 on the largest current [I2] |
| R13 | Cost | Estimated parts cost for one prototype within the $775 value-engineering target (`budget_usd`, a hypothetical control target set under CSH-DDR-002; was $700) | BOM | **Over the value-engineering target by $107:** estimated $882, 13.8 % over, after the parts added to make the design buildable (CSH-DDR-003); savings worth trying are in CSH-DEC-001 [J1, J2] |
| R14 | Buildability | Bolted assembly; no welding; built with a drill, angle grinder, spanners, a hand rivet nut tool, a bench vice and a ladder by two people in 2 days or less | Assembly review | Met by design: 79 bolts and anchors, 36 of them into rivet nuts, no welds [H2]; the hand rivet nut tool and bench vice were added to the tool list by Amish on 2026-10-02 (CSH-DEC-001); build time unverified |
| R15 | Refill interval | 1 design day or more between tank refills | Water balance | Met: 1.41 design days per full tank [C4] |
| R16 | Maintenance | Nozzles cleanable or replaceable without tools in 15 min or less; filter changed in 10 min or less; descaling interval 1 month or longer | Design review; later field log | **At risk** in hard-water areas: scale can block 0.4 mm orifices; not verifiable at TRL 3 |
| R17 | Movability | Can be unbolted and moved to another site by two people in 1 day or less; no part heavier than 40 kg to lift (tank empty) | Mass estimate | Met: heaviest part a front post, 21.0 kg [H1] |

## Assumptions

- Nozzle flow 4 L/h each at 7 bar, eight nozzles, 50 % spray duty cycle while active; this implies a discharge coefficient of 0.24 for a 0.4 mm orifice, to be checked against nozzle datasheets.
- About 87 % of the sprayed water evaporates in the air; the rest drifts away, drips or wets surfaces (estimate).
- Cooling is estimated over a control volume 3.0 m long and 2.0 m high with air crossing it at the wind speed. Real mixing is less even than this.
- Panel output 100 W x 4.5 peak sun hours x 0.75 system factor; battery 12.8 V 25 Ah, 80 % usable.
- Wind: fabric treated as solid with 5 % sag, net normal force coefficient 1.2, S275 steel with a 1.5 factor on wind. All other assumptions are listed in CSH-CAL-001, Table 1.

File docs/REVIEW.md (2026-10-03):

# Review note: CoolShade

## Session 2026-09-25: /populate to a strong TRL 2

### What was done

- `docs/01-problem.md` (CSH-PRB-001 v0.2): problem with cited figures, users, operating environment (design day 38 °C and 25 % RH, humid check 35 °C and 60 % RH), constraints including water hygiene and privacy, out of scope, prior work, open questions; co-design checklist kept.
- `docs/03-requirements.md` (CSH-REQ-001 v0.2): 17 measurable requirements (R1 to R17) with targets, verification method and concept status.
- `docs/02-concept.md` (CSH-PRC-001 v0.2): how it works, 15 numbered components, water, cooling, energy, wind and cost estimates with assumptions, key design choices, integration with HeatMap Node and FieldNode, safety section, open questions.
- `cad/src/concept_media.py`: massing model of a four-post mono-pitch canopy (3.0 x 2.4 m) with shade cloth, panel, equipment enclosure, sensor head, pump, filter, mist line, tank and drain valve, in street context (sidewalk, curb, road, existing bench) with the 1.75 m scale figure.
- `media/`: `hero.png`, `concept-blueprint.png`, `.pdf` and `.svg`, `exploded.png` with callouts 1 to 15, `flow.png` (daily water flow, estimates), `model.glb` and `viewer.html`. No cutaway: the canopy is open, and the enclosed parts (battery, MPPT, controller) are shown in the exploded view.
- `bom/bom.csv`: 16 lines with indicative USD prices, lines 1 to 15 numbered to match the exploded view; `bom/bom-notes.md` updated.
- `README.md`: hero image and links line; Concept rationale, Burning platform, Where it could be used (6 industries, 5 regions), What sparked the idea (origin text kept, trigger added), Problem, Concept, Key components and Safety expanded.
- `docs/pdf/`: branded PDFs of the three controlled documents.
- `project.yaml` unchanged: the pitch and problem still match the concept and the sources found.

### Key results (estimates, to be checked at TRL 3)

| Quantity | Estimate | Requirement |
| --- | --- | --- |
| Shaded area | 7.2 m² | R1 met |
| Mean radiant temperature drop from shade | about 17 °C (published shade sail data, Tempe) | R3 expected met, unverified |
| Air temperature drop at 1 m/s wind | about 1.4 °C averaged, about 2.7 °C while spraying | **R4 not met** at 1 m/s |
| Water per design day | about 85 L (80 L sprayed, 5 L flush) | R7 met |
| Tank endurance | about 1.4 design days | R15 met |
| Energy per design day | about 205 Wh used, about 340 Wh harvested | R8 met |
| Battery usable | about 205 Wh, one design day without sun | R8 met |
| Wind force at 30 m/s | about 4.7 kN on the roof; about 144 MPa in each post as a cantilever | R10 unverified |
| Parts cost | about $735 | **R13 not met**, about 5 % over $700 |

Requirements not met or at risk:

- **R13 (cost) not met:** about $735 against $700.
- **R4 (air cooling of 2 °C) not met at 1 m/s wind**; met in calmer air. The shade, not the mist, gives most of the relief.
- **R5 (no wetting) at risk:** low-pressure nozzles make larger droplets than high-pressure systems.
- **R9 (water hygiene) at risk:** tank water on hot days will be in the 20 to 50 °C *Legionella* growth range; control relies on draining, turnover and disinfection.
- **R16 (maintenance) at risk** in hard-water areas from nozzle scaling.
- **R2 (headroom) marginal:** about 2.1 m under the rear knee braces, which sit at the edge of the waiting area.

### Proposed at TRL 2 (status updated 2026-09-25, see CSH-DDR-002)

1. **Budget.** Options: (a) raise `budget_usd` to $750; (b) cut cost to reach $700, for example by dropping to 60 mm posts with larger knee braces (needs the wind check) or a smaller 80 L tank; (c) keep $700 and treat the anchors and tank as site-supplied. Recommendation: (a), because the post section and tank size carry safety and service margins. **Decided by Amish, 2026-09-25: go with recommendation**, at the later TRL 3 recommendation of $775.
2. **Misting pressure class.** Low pressure (about 7 bar, 12 V, off-grid) versus mid pressure (about 10 to 20 bar, finer droplets, more pump power) versus high pressure (about 70 bar, mains). Recommendation: low pressure for the first concept, with droplet size and wetting as the first thing to check. **Decided by Amish, 2026-09-25: go with recommendation.**
3. **Activation thresholds.** Fixed 32 °C and 60 % RH with PIR presence, versus a heat index or WBGT threshold. Recommendation: fixed thresholds first, since they are easy to explain and audit. **Decided by Amish, 2026-09-25: go with recommendation.**
4. **Fans.** None, versus two 12 V fans (about 20 to 40 W more). Recommendation: none at TRL 2; revisit if R4 remains unmet at TRL 3. **Decided by Amish, 2026-09-25: go with recommendation.**
5. **Water supply.** Tank only, versus tank with an optional mains float valve and backflow preventer. Recommendation: tank as standard, mains optional where local rules allow. **Decided by Amish, 2026-09-25: go with recommendation.**
6. **Canopy size and structure.** 3.0 x 2.4 m, four 80 x 80 x 3 mm posts with knee braces, bolted to an existing slab. Recommendation: keep for TRL 3 and check by calculation. **Decided by Amish, 2026-09-25: go with recommendation.**
7. **Storm practice.** Fabric removed before forecast storms versus fabric designed to stay on. Recommendation: removable fabric. **Decided by Amish, 2026-09-25: go with recommendation.**
8. **Status link.** None, versus a FieldNode-compatible LoRaWAN link reporting counts and levels only. Recommendation: none for the first prototype. **Decided by Amish, 2026-09-25: go with recommendation.**
9. **First site type and partner** for co-design (bus stop, market or queue). No recommendation; still Proposed, awaiting Amish.

### Safety concerns

- *Legionella* and other waterborne pathogens in warm stored water sprayed as an aerosol near the public. This is the main hazard; a named person responsible for water hygiene and a written flush and disinfection routine are needed before any public trial.
- Wind loading of the canopy and anchors; failure could injure people waiting.
- LiFePO4 battery (about 256 Wh): fuse, BMS, cold-charge cutoff, locked ventilated enclosure.
- 7 bar water line; slippery wet ground; work at height and heavy steel during assembly.
- Public perception: people may believe the mist is drinking water or a medical service. Signage is needed.

### Problems and notes

- WebSearch was not available in this session; all sources were checked by fetching the pages directly. No figure was used that could not be verified. The Farnham et al. (2015) and SSRN (2023) prior work entries are cited by title and DOI only; their findings were not used.
- Small parts (MPPT, drain valve, PIR) are partly hidden behind their callout circles in `media/exploded.png`; the legend identifies them. Callouts for frame-like parts (posts, mist line, harness) sit at the part's center, which falls in open space.
- The legacy `cad/src/model.py` placeholder is untouched (TRL 3 work).

### Recommended next step

Review this note and the media, then decide items 1 and 2. If approved, run `/advance-trl3` to check the cooling and wetting estimates against nozzle data, the wind and anchor loads, and the energy budget by calculation, and to produce the parametric model and drawing sheet.

## Session 2026-09-25: TRL 3

On 2026-09-25 Amish asked for this batch of repos to be taken through the usual process with the instruction "you know the drill, nothing gets past TRL 3". He has not reviewed the CoolShade TRL 2 items one by one. This session ran `/advance-trl3` on that instruction and stopped at TRL 3.

### What was done

- `docs/decisions/0001-trl2-review-decisions.md` (CSH-DDR-001 v0.1, status proposed): seven items adopted as recommended for TRL 3 under Amish's 2026-09-25 instruction, open for his review (D1 to D7), and two items left open (O1 budget, O2 first site and partner).
- `docs/04-calcs/01-sizing.md` (CSH-CAL-001 v0.1) and `docs/04-calcs/sizing.py`: shade and space, headroom, nozzle flow and water balance, line draining, droplet evaporation and wetting, cooling, energy and enclosure heat, wind on posts, beams, fabric, anchors and tank, handling, control and electrical, and cost, with a status for every requirement. The script imports the model's parameters and reads the BOM and `project.yaml`; every number in the note is printed by it.
- `cad/src/model.py`: parametric build123d model (posts and braces, roof frame, fabric, base plates and anchors, panel, enclosure with battery and MPPT, sensor head, tank with strap, pump, filter, drain valve and vacuum breaker, mist line loop with nozzles, harness). Exports `cad/step/` and `cad/stl/` for `coolshade-assembly`, `frame` and `water-system`.
- `cad/src/sheets.py` and `cad/drawings/CSH-DWG-001.svg`, `.pdf`, `.png`: general arrangement at Rev P1, 1:50, marked "CONCEPT, NOT FOR FABRICATION" and "PRELIMINARY, NOT FOR FABRICATION". CSH-DWG-001 was free because the concept blueprint is CSH-DWG-010.
- `bom/bom.csv` (16 lines, all priced with a supplier type, $758.00) and `bom/bom-notes.md`.
- `cad/src/concept_media.py` now builds from the model; all of `media/` was re-rendered and every image checked. The temporary `media/_views*` folders were deleted. No cutaway (the canopy is open), so the kit's origin-centered cut did not matter here.
- CSH-PRB-001, CSH-PRC-001 and CSH-REQ-001 revised to v0.3; `README.md` and `project.yaml` (`trl: 3`, `trl_target: 3`, evidence list) updated. `budget_usd`, pitch and problem unchanged. PDFs rebuilt in `docs/pdf/`.

Detail changes found necessary by the calculations, all within the adopted choices: knee braces shortened to 400 mm down and 400 mm along (the TRL 2 braces left about 2.11 m of headroom, below R2); a vacuum breaker at the loop's high point (anti-drip nozzles would stop the line from draining); the mist line made a closed loop with a fall toward the down pipe; and a strap on the tank (an empty tank tips in a 30 m/s gust). They add $23.

### Requirement status (CSH-CAL-001, Table 3)

3 not met, 3 at risk, 1 not verifiable at TRL 3, 10 met (5 by calculation, 4 by design, 1 on published evidence).

| ID | Status | Key number |
| --- | --- | --- |
| R4 Air cooling | **Not met** | 1.35 °C averaged (2.71 °C while spraying) at 1 m/s; met only below 0.68 m/s |
| R10 Wind | **Not met** (conservative case) | Fabric edge pull loads the 50 mm long beams to 3.52 times capacity at 30 m/s; fabric must come off above about 16 m/s. Posts 0.29; anchors need about 6.4 kN each, not verifiable |
| R13 Cost | **Not met** | $758: +8.3 % on $700 and +1.1 % on the proposed $750; steel prices look low |
| R8 Energy | At risk | Battery covers 1.005 design days, no margin; no charging above about 41 °C air |
| R9 Hygiene | At risk | Line drains in about 27 s, water under 24 h old with a 95 L daily drain-and-refill, but tank water about 34 °C |
| R16 Maintenance | At risk | Scaling of 0.4 mm orifices; not verifiable on paper |
| R5 Wetting | Not verifiable at TRL 3 | Needs Dv0.9 below about 81 µm at 7 bar (humid edge); no droplet data |
| R1, R2, R7, R15, R17 | Met | 6.30 m² shadow or more; 2,234 mm headroom; 85 L used, 95 L drawn; 1.41 days per tank; heaviest part 22.0 kg |
| R6, R11, R12, R14 | Met by design | Stop within 30 s; PIR only; 15 A fuse; bolted, no welds |
| R3 | Met on published evidence | About 17.3 °C for shade sails; unverified for this fabric |

Key numbers: 32 L/h while spraying; 203.8 Wh used and 337.5 Wh harvested per design day; about 143 kg of steel; post stress 54 MPa unfactored in a 30 m/s gust (the TRL 2 figure of about 144 MPa was an upper bound).

### Decisions recorded (CSH-DDR-001)

Adopted as recommended for TRL 3 under Amish's 2026-09-25 instruction, now **Decided by Amish, 2026-09-25: go with recommendation** (CSH-DDR-002): D1 low-pressure 7 bar misting; D2 fixed thresholds (32 °C, 60 % RH, presence in 2 min, tank level); D3 no fans at TRL 3; D4 tank standard, mains optional; D5 3.0 x 2.4 m bolted four-post canopy; D6 removable fabric before storms; D7 no status link. No pitch or problem rewording was recommended, so none was applied. CoolShade uses no shared component from this batch (FieldNode link not fitted), so there is no interface conflict.

### Still awaiting Amish at the end of TRL 3 (status updated 2026-09-25, see CSH-DDR-002)

1. **O1, budget.** The TRL 2 recommendation was to raise `budget_usd` to $750. It is not applied: `budget_usd` stays at $700. The parts cost is now $758, over both figures. Options: (a) $775, which covers the TRL 3 changes with a little room for quotes; (b) $750 and cut the tank to 100 L or accept site-supplied anchors; (c) keep $700 and treat the tank and anchors as site-supplied. Recommendation: (a), because the steel prices look low and quotes may raise them further. **Decided by Amish, 2026-09-25: go with recommendation** ($775).
2. **O2, first site type and co-design partner.** No recommendation; stays open (Proposed, awaiting Amish).
3. **New, R10 fabric-on wind case.** Options: (a) restate R10 as "frame and anchors survive 30 m/s with the fabric removed; fabric fitted only in forecast gusts below 15 m/s (54 km/h)", which the design meets on paper; (b) keep R10 and upsize the long beams (for example to 80 x 80 mm), which costs money and mass; (c) keep R10 and fit a cord lacing that releases the fabric at a set load. Recommendation: (a) now, with (c) studied at TRL 4 if allowed later, because the fabric's porosity and stretch are unknown and a release that fails safe is worth having. **Decided by Amish, 2026-09-25: go with recommendation**: (a) applied; (c) on hold with TRL 4.
4. **New, R4 and fans (revisit under D3).** R4 remains unmet at 1 m/s. Options: (a) relax R4 to "2 °C while spraying", which is met (2.71 °C); (b) add two 12 V fans (about 20 to 40 W, which would break the R8 energy balance without a larger battery); (c) keep R4 as a stretch target. Recommendation: (a), because the shade gives most of the relief and the battery has no margin for fans. **Decided by Amish, 2026-09-25: go with recommendation.**
5. **New, R8 energy margin.** Options: (a) a 25 Ah battery instead of 20 Ah (about 1.26 design days); (b) a latching drain valve (1.14 days, but it does not open on power loss). Recommendation: (a), keeping the fail-safe normally open valve. **Decided by Amish, 2026-09-25: go with recommendation.**

Suggestion only, not in the repo: a continuous spray at half the flow (smaller nozzles) instead of 20 s pulses would give a steadier temperature drop at the same water use.

### Safety concerns

- *Legionella* stays the main hazard: tank water sits at about 34 °C on design days. The daily drain-and-refill, line draining and weekly disinfection need a named responsible person, and no public trial should run without a hygiene plan accepted by the local health authority.
- Wind: on the conservative case the roof beams are overloaded with the fabric on above gusts of about 16 m/s. Removing the fabric before storms is structurally necessary, and the anchors and slab must be checked by an engineer at each site. The tank must be strapped.
- Battery heat: in 45 °C air the enclosure reaches about 48.6 °C, so charging stops; the BMS must enforce the 45 °C charge limit.
- 7 bar water line, slippery wet ground, work at height with heavy steel during assembly.
- Public perception: signage that the mist is not drinking water or a medical service.

### Gaps and notes

- Citations: WebFetch of Crossref on 2026-09-25 confirmed the metadata of the two prior-work entries: Farnham, Emura and Mizuno, "Evaluation of cooling effects: outdoor water mist fan", *Building Research and Information* 43(3), 2015; and Zhao et al., "Assessment of Sun Sail Shading, Mist-Spray Cooling, and Their Hybrid System in Improving Outdoor Thermal Comfort in a School Courtyard", SSRN, 2023. CSH-PRB-001 now names the authors. Their findings were not read and are not used.
- Assumptions that only data or tests can settle: nozzle flow and droplet spectrum, fabric porosity and stretch, the 87 % evaporation fraction, pump draw, enclosure heat and tank temperature.
- The exploded view is dense: the MPPT (7), drain valve (14) and PIR are small and partly hidden; callouts for the mist line (12) and harness (15) sit in open space near their thin runs. The legend identifies them.
- The model's roof beams and braces are solid massing bodies, so the STEP volume overstates steel mass; CSH-CAL-001 computes mass from the section properties instead.
- Existing material beyond TRL 3: `build-log/README.md` (scaffold) is present, untouched and not extended. `electronics/` and `firmware/` are empty. No test, build or firmware material exists.

### Recommended next step

TRL 4 is on hold by Amish's instruction; this repo stops at TRL 3. Amish's review is needed on the budget (O1), the first site (O2) and the new R10, R4 and R8 items above. For the record only, TRL 4 would need: nozzle flow and droplet size measured at 7 bar at both the design day and the humid edge; a bench spray and drain rig showing the line empties past the anti-drip nozzles; wind data or a test for the chosen fabric; a lab test report (TST, `environment: lab`); and build log entries. None of this has been started.

## Session 2026-09-25: recommendations accepted

On 2026-09-25 Amish wrote, in chat: "i accept all your recommendations, go with them across all repos." Every item with a recommendation is now "Decided by Amish, 2026-09-25: go with recommendation" and recorded in `docs/decisions/0002-recommendations-accepted.md` (CSH-DDR-002 v0.1). CSH-DDR-001 is revised to v0.2 and the earlier lists in this note are annotated.

### Decisions applied and what changed

| Item | Decision | Before | After |
| --- | --- | --- | --- |
| D1 to D7 | Pressure class, thresholds, no fans, tank supply, canopy structure, removable fabric, no status link | Adopted for TRL 3, open for review | Decided; no design change |
| O1 Budget | $775 (TRL 3 recommendation, supersedes $750) | `budget_usd` 700 | `budget_usd` 775 |
| R10 wind | Restate: frame and anchors survive 30 m/s with fabric removed; fabric on only in forecast gusts below 15 m/s | Not met: long-beam utilization 3.52 with fabric on at 30 m/s; anchors about 6.4 kN | Met on paper: fabric off at 30 m/s posts 0.14, purlins 0.15; fabric on at 15 m/s beams 0.88; anchors about 2.8 kN, per site |
| R10 release lacing | Study at TRL 4 | Option | Decided, on hold (TRL 4) |
| R4 cooling | Restate as 2 °C while spraying; no fans | Not met: 1.35 °C averaged at 1 m/s | Met: 2.71 °C while spraying at 1 m/s (holds to 1.35 m/s) |
| R8 energy | 25 Ah battery, keep normally open drain valve | At risk: 20 Ah, 1.005 design days | Met: 25 Ah, 1.256 design days |
| Parts cost | Consequence of the battery | $758.00 | $773.00 ($2.00, 0.3 %, under $775) |

Files changed: `project.yaml` (`budget_usd`, evidence list); `README.md` (budget, concept and results text, battery, new "What sparked the idea"); `docs/01-problem.md` (CSH-PRB-001 v0.4); `docs/02-concept.md` (CSH-PRC-001 v0.4); `docs/03-requirements.md` (CSH-REQ-001 v0.4, R4, R10 and R13 targets); `docs/04-calcs/sizing.py` and `01-sizing.md` (CSH-CAL-001 v0.2, new lines G13 and G14); `docs/decisions/0001-trl2-review-decisions.md` (v0.2); `bom/bom.csv` (line 6 battery 25 Ah, $85 to $100; line 3 note) and `bom/bom-notes.md`; `cad/src/model.py` (battery envelope 80 to 100 mm wide), STEP and STL re-exported; `cad/src/sheets.py` and `cad/drawings/CSH-DWG-001.*` (Rev P1 to P2: battery and wind notes, anchor load 6.4 to 2.8 kN); `cad/src/concept_media.py` and all of `media/` re-rendered (key figures, battery label); `docs/pdf/` rebuilt. The site footer is now designmolecule.com in every regenerated file.

### Requirement status now (CSH-CAL-001 v0.2)

| Status | Requirements |
| --- | --- |
| Not met | None (was R4, R10, R13) |
| At risk | R13 cost ($773 against $775; steel prices look low), R9 water hygiene (tank water about 34 °C), R16 nozzle scaling |
| Not verifiable at TRL 3 | R5 wetting (needs Dv0.9 below about 81 µm at 7 bar) |
| Met | R1, R2, R3 (published evidence), R4, R6, R7, R8, R10 (on paper; anchors per site), R11, R12, R14, R15, R17 |

### Still awaiting Amish

- O2, first site type (bus stop, market or queue) and co-design partner: no recommendation was made, so it stays Proposed, awaiting Amish.

### Cross-repo actions

- None. No FieldNode status link is fitted (D7), so CoolShade asks nothing of another repo. HeatMap Node remains a related project only.

### Safety

The safety sections are unchanged in substance. The wind rule is now explicit: the fabric goes on only when forecast gusts are below 15 m/s (54 km/h) and comes off before storms. *Legionella* control (R9) remains the main hazard.

### TRL

`trl: 3` and `trl_target: 3` are unchanged. TRL 4 remains on hold by Amish's instruction: the load-release lacing study, nozzle and droplet measurement, wind tests, firmware and any build or purchase have not been started.

## Session 2026-09-26: product appearance model and photoreal renders

Amish chose CoolShade for the first batch of product renders on 2026-09-26. This session adds an appearance model for photoreal renders; it changes no design figure, requirement, calculation, drawing or BOM line.

### What was done

- `cad/src/product_model.py` (new): `product_parts()` returns 102 named parts (64 shell, 32 internal, 6 context) with colour, material, BOM line, group and explode offset; `TITLE` and `RENDER_VIEWS` define three views: "hero" (canopy, water plant and context), "exploded" and "detail" (the water plant only, since the mannequin makes the hero scene tall). All dimensions, positions and interfaces come from `PARAMS` and `derived()` in `cad/src/model.py`, and its `box()`, `rod()`, `zcyl()` and `shs()` helpers are reused.
- `README.md`: the hero image now points to `media/render-hero.png`, and the links line starts with the exploded render. The render files are produced separately by the orchestrator.

What the appearance model adds:

- Structure: posts with rounded SHS corners; knee braces with bolted end sleeves; base plates with anchor washers and nuts; roof frame with black end caps.
- Roof: shade cloth with a reinforced hem band and 28 eyelets; 100 W panel with an aluminium frame, 36 cells, busbars, glass, clamps, rail caps and a junction box on slotted rails.
- Mist system: loop on hanger clips, eight slip-lok tees with brass nozzles, a vacuum breaker at the front, and a riser clipped up the rear left post.
- Power and sensing: enclosure with a door, a window onto the MPPT controller's lit display, a lock, hinges, a rain hood, a lit green status lamp, a label, glands and post clamps, with the battery, MPPT and controller board inside; louvred radiation shield with its probe, arm and clamp; PIR with a Fresnel dome.
- Water plant: opaque tank with rolling hoops, screw lid, lock hasp, "potable water only" label, outlet tap, anchor cleats, strap, ratchet and post eye; vented pump box with a window onto the pump; clear-bowl filter with its cartridge; solenoid drain valve; hoses.
- Context: compact paved patch with a curb, an existing slatted bench and the shared clay mannequin (1.75 m, standing) under the canopy.

### Differences from model.py (appearance only)

Each item is Proposed, awaiting Amish.

1. **Filter in the suction path.** `model.py` routes the supply hose from the tank straight to the pump, while the precis says the pump draws through the filter. The appearance model keeps the model.py hose and adds a short hose from the filter to the pump box. Recommendation: at the next model update, reroute the model.py hose from the tank to the filter and then to the pump, and leave the render as is until then.
2. **Pump shelf bracket.** `model.py` shows the pump box about 10 mm clear of the rear left post with no support. The appearance model adds a steel shelf bracket bolted to the post. Recommendation: add the bracket to `model.py` and to BOM line 16 hardware (no new line or cost).
3. **Drain valve connection.** `model.py` has no pipe between the riser and the drain valve. The appearance model adds a short tee from the riser and a 40 mm downturned spout below the valve envelope. Recommendation: adopt, since the valve must connect to the line to drain it.
4. **Enclosure details outside the model.py box.** The rain hood adds 12 mm at the sides and 6 mm on top; post clamps wrap the post; hinges, lock and lamp stand a few millimeters proud of the door. Recommendation: adopt as appearance detail; the 420 x 320 x 160 mm envelope is unchanged.
5. **Tank lid and hoops.** The screw lid and neck add about 50 mm to the 700 mm tank height, and the rolling hoops add 7 mm to the radius. Recommendation: adopt; this is typical of a 120 L drum and does not affect the post, strap or pump positions.
6. **Sensor head and PIR shapes.** The shield plates are louvred cones on spacer rods instead of flat discs; the PIR housing is 40 mm tall with a dome below it, ending 5 mm lower than the model.py block. Recommendation: adopt.
7. **Scene context.** The paved patch (3.7 x 2.9 m with a curb) replaces the larger sidewalk, curb and road of `concept_media.py`, and the bench moves 40 mm toward the rear and is shown as a slatted timber bench. Recommendation: keep for product renders only; the concept media are unchanged.

The shade cloth, beams, posts, panel, mist line, nozzle positions and enclosure envelope keep the model.py dimensions (the cloth has 40 mm rounded corners inside the full-size hem).

### Checks

All parts are valid solids and tessellate at `tessellate(0.05, 0.1)`; `.kit/product_export.py` exports them; `python .kit/render.py --check` passes. Matplotlib previews (clear parts omitted) were used to check the three views.

### TRL

This is an appearance model only: no tolerances, fabrication detail, PCB layout or build work. `trl: 3` and `trl_target: 3` are unchanged, and TRL 4 remains on hold by Amish's instruction.

## Session 2026-09-27: kit 1.5.0 and image quality

- Kit 1.5.0 synced: STANDARDS v1.5 (sections 12 to 15: product renders, storefront images and image quality, public release, authorship and signing), `.kit/cards.py`, `.kit/image_qc.py`, `.kit/release_gate.py`, issue templates, and the `/render-product` and `/release` commands. `CLAUDE.md` now matches `.kit/CLAUDE.md`.
- Every `media/render-*.png` recaptioned from its original render with the new layout: the title, concept label and repository sit in a band above the render and the view note in a band below it, each line wrapped to the image width, so no text overlaps other text or the render or runs off the image. `media/card.png` and `media/social-preview.png` regenerated with the same rules.
- `python .kit/image_qc.py` and `python .kit/release_gate.py` pass. trl stays 3.

## Session 2026-09-30: constructable design and prototype build plan (kit 1.7.0)

On 2026-09-30 Amish approved the build plan format and asked for it across all repos, with outstanding decisions kept out of the build plan in a separate design decisions register, and wrote: "If you are realising that the design cannot be built as per concept - fix the design assumptions to match and be physically feasible as you draw the illustrations." This session installed kit 1.7.0 and ran `/build-plan` on that instruction. It stopped at TRL 3: nothing was built, bought or tested.

### What was done

- Kit 1.7.0 installed (`.kit/`, `.claude/commands/`); `CLAUDE.md` replaced by `.kit/CLAUDE.md`.
- `cad/src/model.py` rewritten as a constructable model: 61 parts, each modelled as it is made or bought, with every bolt and cable hole cut, and 117 build123d constructability checks (`python cad/src/model.py --check`): overlap of every neighbouring pair, contact at every joint, headroom and the sensor shield's height. All pass. STEP and STL re-exported (`coolshade-assembly`, `frame`, `water-system`).
- `docs/decisions/0003-design-for-construction.md` (CSH-DDR-003 v0.1, Draft): every change, made under Amish's 2026-09-30 instruction to make the design physically buildable; open for his review.
- `docs/05-build-plan.md` (CSH-BLD-001 v0.1): the illustrated build plan, with 16 making sketches (`cad/drawings/CSH-DWG-101` to `116`), 13 joint close-ups, 17 assembly step pictures, an overview, a slab layout, post and beam hole charts, block wiring and the water circuit, all drawn from the model by `cad/src/build_plan_media.py`.
- `docs/06-design-decisions.md` (CSH-DEC-001 v0.1): 3 open decisions, 13 items to confirm when parts are bought or the site is chosen, and every decision made.
- `docs/04-calcs/sizing.py` and `01-sizing.md` (CSH-CAL-001 v0.3), `docs/02-concept.md` (CSH-PRC-001 v0.5), `docs/03-requirements.md` (CSH-REQ-001 v0.5), `bom/bom.csv`, `bom/bom-notes.md`, `README.md` (links line and "Building the prototype"), `project.yaml` (`design_state: constructable`, evidence list).
- General arrangement `cad/drawings/CSH-DWG-001` Rev P4 and the concept media (`media/hero.png`, `exploded.png`, `concept-blueprint.*`, `flow.png`, `model.glb`, `viewer.html`) regenerated from the new model. PDFs rebuilt in `docs/pdf/`.

### Design changes made for construction (CSH-DDR-003)

1. Posts moved out across the sidewalk from 2,100 to 2,350 mm between centres so the long beams sit on the post tops at the roof's edges and the cloth has a tube under every edge; end beams moved to the roof ends.
2. Long beams horizontal and square on the post tops; end beams, purlins and a new panel bearer cut 7° off square to butt against the beam faces.
3. Head cleats at every post top and base cleats at every post foot (angle, bolted); no welding.
4. Roof joints made with 50 x 50 x 5 mm angle frame cleats; every bolt into a closed beam goes into an M8 or M5 steel rivet nut, so nothing stands proud under the cloth.
5. Knee braces with flattened, bent, bolted ends; bends 350 mm down and along (was 400 mm), lowest point 2,223 mm.
6. Solar panel moved to the rear edge on two rails and four L-feet on the panel bearer and the rear beam; a 1,020 x 670 mm notch in the cloth under it; purlins moved from 450 to 530 mm off centre to frame the notch.
7. Enclosure on two through-bolted rails; battery, MPPT and controller board placed inside; three cable glands.
8. Sensor arm made from 40 x 40 x 4 mm angle on the street face of the front right post, raised to 2.4 m (shield's lowest plate 2,266 mm); bought shield unit hung on one bolt; PIR on a bracket.
9. Pump, filter and drain valve on an equipment plate on the rear left post; the down pipe ends in the drain valve with a tee to the pump outlet; hoses tank to filter to pump (REVIEW 2026-09-26, items 1 to 3).
10. Tank moved clear of the post base; strap round tank and post; two stop cleats with M10 anchors.
11. Mist line loop moved 70 mm inboard of the long beams and under the end beams, on 18 hanger clips.
12. Cables routed inside the posts and beams through grommeted holes.
13. Added parts needed for the decided function: a tank low-level switch (R6) and an I2C bus extender for the 7 m sensor cable.

### Key results (CSH-CAL-001 v0.3)

- Requirement status: **1 over its value-engineering target (R13 cost: estimated $882.00 against the $775 target, +13.8 %)**, 2 at risk (R9, R16), 1 not verifiable at TRL 3 (R5), 13 met. Before this session: none not met, 3 at risk.
- Headroom 2,223 mm (R2 met, was 2,234); clear floor 2.72 x 2.27 m (8 standing, 3 seated and a wheelchair); nozzle tips 2,559 and 2,835 mm.
- Steel 167 kg; heaviest part a front post, 21.0 kg; 79 bolts and anchors.
- Fabric off at 30 m/s: posts 0.14, panel bearer 0.02, purlins 0.07, rear beam 0.11; anchors about 2.8 kN factored. Largest rivet nut pull about 0.16 kN factored.
- Mist line 11.91 m, 0.40 L, drains in about 30 s.

### Proposed, awaiting Amish (see CSH-DEC-001)

1. R14 tool list: add a hand rivet nut tool and a bench vice (recommended).
2. First site type and co-design partner (no recommendation; carried over).

### Stale media (made on Amish's Mac; not regenerated here)

The design changed visibly, so `media/render-hero.png`, `media/render-exploded.png`, `media/render-detail.png`, `media/card.png` and `media/social-preview.png` are stale: they show posts on the 2.1 m grid, the panel in the middle of the rear half on top of the cloth, the tank against the post and the concept braces. `cad/src/product_model.py` still builds the concept appearance (it reads `model.py`'s parameters, so the posts move, but its panel, rails, tank and equipment details follow the concept); it needs updating before the renders are redone.

### Safety

Unchanged in substance. The build plan adds safety stops S1 to S9 (slab drilling, lifting posts, work at height, battery, pressurizing the line, misting near people, fitting the cloth, public use). *Legionella* control (R9) remains the main hazard.

### Recommended next step

Amish reviews CSH-DDR-003 and the open decisions in CSH-DEC-001; the Value engineering section there holds the $775 target, the $882 estimate and the savings worth trying. TRL 4 (building to this plan) stays on hold by his instruction.

## Session 2026-10-02: open decisions decided

Amish approved every recommendation for the open decisions on 2026-10-02: "i approve your recommendations for all 555 open decisions."

### Decisions recorded

Two, both moved to "Decisions made" in CSH-DEC-001: R14's tool list gains a hand rivet nut tool and a bench vice, and the rivet nuts are kept (CSH-DDR-003, A2); the first site type is a market lane with the market operator as co-design partner in a hot, dry city, with a farmers' market operator in the Phoenix area as the first candidate to approach and Arizona State University's urban heat researchers as the candidate measurement partner.

### Documents changed

- `docs/06-design-decisions.md` CSH-DEC-001 v0.3: decisions made; open decisions section now reads "None"; To confirm item 10 updated for a market lane site.
- `docs/decisions/0003-design-for-construction.md` CSH-DDR-003 v0.3: A2 decided as recommended (status Draft kept).
- `docs/03-requirements.md` CSH-REQ-001 v0.7: R14 restated with the hand rivet nut tool and bench vice.
- `docs/04-calcs/01-sizing.md` CSH-CAL-001 v0.5: R14 row text only; no figures changed.
- `docs/01-problem.md` CSH-PRB-001 v0.5 and `docs/02-concept.md` CSH-PRC-001 v0.7: first site type and candidate partners.

### Follow-up actions to carry approved decisions into the design

1. Decision 2 (model, drawings, pictures): set the slab, anchors, setback and orientation of the first build for a market lane once a site is offered; the model and build plan pictures now show a curbside stop layout.
2. Decision 2 (docs): carry the market lane into the water hygiene plan (To confirm item 11), naming the local health authority and responsible person once a site is offered.

### Points found in the review

- The design for construction (DDR-003, P1 to P16) was still "open for his review" but had no row in the open decisions table; the recommendation was to accept it, with steel quotes taken before buying. Amish accepted it later on 2026-10-02 (see the next session).
- The *Legionella* water hygiene plan ("To confirm" item 11) is a safety stop for any public trial, not a purchase check; it belongs with the open decisions or the safety stops.
- The constructable design is $882 against the $775 target, $107 (13.8 percent) over, and the steel at about $1.61 per kg including cutting, drilling and galvanizing looks low for small quantities, so the gap may widen.

## Session 2026-10-02: design-for-construction changes accepted

Amish, 2026-10-02: "APPROVED: Design-for-construction changes in 10 repos (CityTwin, CoolShade, PalletPilot, Heliolite, PotholeLog, EarthPress, ReadyKit, CellCheck, CargoMule and ThermaCart)". This accepts the design-for-construction changes P1 to P16 in Table 1 of CSH-DDR-003, with their knock-on changes in Table 2, which were left open for his review when the open decisions were decided earlier the same day. No other item is decided by it. trl stays 3; no build or test work was done, and the model, BOM, calculations and pictures are unchanged.

### Documents changed

- `docs/decisions/0003-design-for-construction.md` (CSH-DDR-003 v0.4, status Draft): status line now "accepted" with Amish's words.
- `docs/06-design-decisions.md` (CSH-DEC-001 v0.4): Decisions made row added, dated 2026-10-02; the 2026-09-30 row no longer calls the changes open for review.
- `docs/05-build-plan.md` (CSH-BLD-001 v0.2): section 2 says CSH-DDR-003 is accepted.
- PDFs regenerated.

### Recommended next step

Take steel quotes before buying, as noted in the previous session. TRL 4 remains on hold by Amish's instruction.

## Session 2026-10-02: approved follow-ups carried out

Amish approved on 2026-10-02 that every follow-up action from the open-decision sign-off be carried out. trl stays 3; nothing was built, bought or tested.

### Follow-ups (2)

| # | Follow-up | Result |
| --- | --- | --- |
| 1 | Set the slab, anchors, setback and orientation of the first build for a market lane | Not done: needs a site to be offered; the model and pictures keep the curbside stop until then (see To confirm item 10) |
| 2 | Carry the market lane into the water hygiene plan (To confirm item 11) | Done. Item 11 and safety stops S7 and S9 now name the market operator's manager and the environmental health authority by role; the authority itself is named once a site is chosen |

No model, BOM, calculation or picture change was called for: requirement statuses, cost and mass are unchanged. The appearance model (`cad/src/product_model.py`) already follows `cad/src/model.py`; render scenes were exported again to /home/claude/renders/coolshade.

### Documents changed

- `docs/06-design-decisions.md` (CSH-DEC-001 v0.5), `docs/05-build-plan.md` (CSH-BLD-001 v0.3); PDFs regenerated.

### Cross-repo actions

None.

## 2026-10-02: photoreal renders redone on the constructable design

Rendered with Blender Cycles on Amish's Mac from the updated appearance model; captioned with `.kit/photo_caption.py`; `media/card.png` and `media/social-preview.png` regenerated with `.kit/cards.py`. Views: hero, exploded, detail. image_qc passes. Appearance deviations are those logged above as proposed, awaiting Amish.

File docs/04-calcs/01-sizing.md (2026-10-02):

---
doc_id: CSH-CAL-001
title: CoolShade sizing calculations
project: CoolShade
doc_type: Calculation
version: "0.5"
status: Draft
date: '2026-10-02'
author: Amish Chadha
license: CERN-OHL-S-2.0
revisions:
- version: "0.1"
  date: '2026-09-25'
  author: Amish Chadha
  change: First issue for TRL 3 (shade and space, headroom, misting and water, droplets and wetting, cooling, energy, wind and structure, handling, control and electrical, cost)
- version: "0.2"
  date: '2026-09-25'
  author: Amish Chadha
  change: Recommendations accepted by Amish (DDR-002)
- version: "0.3"
  date: '2026-09-30'
  author: Amish Chadha
  change: 'Constructable design (CSH-DDR-003): post grid, headroom, mist line, masses, panel support, rivet nuts, fixings and cost updated; R13 not met against $775'
- version: "0.4"
  date: '2026-10-01'
  author: Amish Chadha
  change: Budget treated as a value-engineering target
- version: "0.5"
  date: '2026-10-02'
  author: Amish Chadha
  change: "R14 row text updated for the tool list decided on 2026-10-02; no figures changed"
---

# CoolShade sizing calculations

On paper, CoolShade meets thirteen of its seventeen requirements (seven by calculation, four by design, one on published evidence and one, R10, on paper with the anchors to be confirmed per site), has two at risk (R9 water hygiene and R16 scaling), one that cannot be judged at TRL 3 (R5 wetting) and one over its value-engineering target: R13, cost, because the parts added to make the design buildable (CSH-DDR-003, version 0.3 of this note) bring the estimated parts cost to $882.00 against the $775 target (a hypothetical control target), $107 over; savings worth trying are in CSH-DEC-001. Version 0.3 also takes the constructable geometry: posts on a 2,800 x 2,350 mm grid, flattened-end knee braces with a lowest point of 2,223 mm, a longer mist line, the panel on a bearer and L-feet at the rear edge, and 167 kg of steel. Version 0.2 applies the recommendations Amish accepted on 2026-09-25 (CSH-DDR-002): R4 is restated as 2 °C while spraying (2.71 °C is met; it was 1.35 °C averaged against 2 °C, not met); R10 is restated as surviving 30 m/s with the fabric removed and keeping the fabric on only in forecast gusts below 15 m/s (met on paper; the original fabric-on 30 m/s case overloads the 50 mm roof beams about 3.5 times); the battery grows from 20 Ah to 25 Ah (1.26 design days without sun, was 1.005); and `budget_usd` rises from $700 to $775, against which the $773 parts cost is $2 under but at risk because the steel prices look low. The calculations changed four details of the TRL 2 concept: shorter knee braces for headroom, a vacuum breaker so that the mist line can drain past its anti-drip nozzles, a closed mist line loop, and a strap on the tank, which tips over in a 30 m/s gust when empty. Every number in this note is printed by `docs/04-calcs/sizing.py`; the tag in brackets, for example [G7], is the line of that script's output that carries it.

> **Safety:** These are first-principles screening estimates for a paper proof of concept. They are not a structural design to any code, they do not show that the mist is safe to breathe, and they do not replace an engineer's check of the frame, anchors and slab at a real site, or a water hygiene plan approved by the local health authority. See CSH-PRC-001, Safety.

## Scope and method

The note checks every requirement in CSH-REQ-001 v0.5 against the design in CSH-PRC-001 v0.5 and the parametric model `cad/src/model.py`. The script imports the model's `PARAMS` and derived dimensions, so the post grid, roof heights, brace geometry, nozzle heights and mist line length used here are the ones in the STEP files and in drawing CSH-DWG-001. It also reads `bom/bom.csv` and `budget_usd` in `project.yaml`. Run it from the repo root with `python docs/04-calcs/sizing.py`.

The design day is unchanged from CSH-REQ-001: 38 °C air at 25 % relative humidity, clear sky, wind about 1 m/s, 5 h of misting demand and 4.5 peak sun hours. The humid edge is the wettest air in which the controller still mists: 32 °C at 60 % relative humidity.

## Assumptions

*Table 1. Main assumptions.*

| Area | Assumption | Basis |
| --- | --- | --- |
| Nozzles | Eight 0.4 mm swirl nozzles at 7 bar (100 psi), 4 L/h each; spray 20 s on, 20 s off (50 %) during 5 h of demand; 87 % of the sprayed water evaporates in the air | TRL 2 estimates; flow to confirm from the maker's data |
| Air | Density 1.15 kg/m³, specific heat 1,006 J/(kg K), latent heat 2.43 MJ/kg; control volume 3.0 m long and 2.0 m high crossed at the wind speed; vapor diffusivity 2.6 x 10⁻⁵ m²/s; viscosity 1.9 x 10⁻⁵ Pa s | Handbook values near 35 °C |
| Droplets | Surface at the wet-bulb temperature (Stull approximation); Stokes settling; nozzle jet carries droplets 300 mm below the tip before they move with the air; head height 1.5 m | Screening model; jet length assumed |
| Energy | Pump 60 W while spraying; controller and sensors 1.2 W continuous; normally open drain valve 5 W while held shut; 100 W panel, 4.5 peak sun hours, 0.75 system factor; 320 Wh battery (12.8 V 25 Ah, CSH-DDR-002), 80 % usable | TRL 2 estimates |
| Enclosure | 200 W/m² on its worst face under the cloth, absorptance 0.5, film coefficient 10 W/(m² K), 5 W internal loss; LiFePO4 charging stops above 45 °C | Screening values; typical cell data |
| Wind | 30 m/s gust, air 1.2 kg/m³; net normal force coefficient 1.2 on the whole roof with the fabric treated as solid; center of pressure a quarter of the depth off center; friction 0.04 on each face; drag 2.0 on square sections and 0.8 on the tank; roof edge band 100 mm | Conservative screening values, not a code check |
| Steel | S275 (275 MPa yield), density 7,850 kg/m³; partial factor 1.5 on wind, 0.9 on dead load | Common minimum grade for galvanized hollow sections |
| Fabric | Sags 5 % of its 2.4 m span under load | Assumed; knitted cloth stretch data needed |
| Tank | 8 kg empty | Assumed |
| Space | 0.5 m² per standing person; wheelchair space 0.8 x 1.2 m; existing bench 1.5 x 0.42 m | R1 and site context |

## A. Shade and space (R1)

- **Shade area.** The roof is 7.20 m² in plan and 7.26 m² on the slope [A1]. Its shadow is 7.20 m² with the sun overhead and at least 6.30 m² for any sun elevation of 45° or more [A2], so R1's 6 m² is met.
- **Where the shadow falls.** With the sun at 60° elevation from the street side, only 2.11 m² of the shadow falls inside the canopy's own footprint; from along the curb, 3.33 m² [A2]. The shaded waiting spot moves with the sun, so the sun path check at each site (R1's verification) matters more than the roof area.
- **Space.** The clear floor between the posts is 2.72 x 2.27 m (6.17 m²; it was 2.72 x 2.02 m before the posts moved out under CSH-DDR-003). After the tank and pump, the bench and one wheelchair space, 4.27 m² remains, room for eight people standing plus three seated [A3]. R1 (six people and one wheelchair space) is met.

## B. Headroom (R2)

- The long beams are horizontal and sit on the posts at the roof's edges (CSH-DDR-003); their underside is 2,912 mm at the front and 2,618 mm at the rear [B1].
- At TRL 2 the rear knee braces dropped 520 mm below the beam, leaving about 2,110 mm at the post face, below R2's 2,200 mm; the TRL 3 concept shortened them to 400 mm (low end 2,234 mm). The constructable braces have flattened ends 45 mm long bolted flat to the post and beam, so their bends are 350 mm down the post and 350 mm along the beam, and the bottom of the lower flattened end, the lowest point overhead, is at 2,223 mm at the rear posts and 2,517 mm at the front posts [B2].
- The nozzle tips are at 2,559 mm (rear row) and 2,835 mm (front row); the sensor arm is at 2,400 mm, and the shield's lowest plate at 2,266 mm, outboard of the front right post [B3]. R2 is met, with 23 mm to spare at the rear braces.

## C. Misting and water (R7, R15, R9)

- **Nozzle flow.** A 0.4 mm orifice at 7 bar would pass 16.9 L/h as an ideal jet. The assumed 4 L/h implies a discharge coefficient of 0.24, which is plausible for a swirl nozzle that trades flow for fine atomization, but it must be confirmed from the maker's data [C1].
- **Daily water.** Eight nozzles spray 32 L/h, or 16 L/h averaged over the cycle, so the design day sprays 80 L and uses 85 L with the 5 L flush; about 69.6 L evaporates [C2]. R7 (100 L per day) holds up to 4.75 L/h per nozzle. At 5 L/h the day would use 105 L and R7 would not be met [C3].
- **Tank.** A full 120 L tank lasts 1.41 design days [C4]; R15 is met.
- **Drain-and-refill routine.** R9 limits tank water to 48 h old. Topping up a part-full tank never guarantees this, so the routine is to drain the residual and refill. Filling 95 L each design day leaves about 10 L to drain at the next visit, keeps every liter under 24 h old and draws 95 L per day; filling to 120 L and draining the rest would draw 120 L and miss R7 [C5].
- **Pump.** The hydraulic power is 6.2 W, so the assumed 60 W draw implies 10 % wire-to-water efficiency [C6], a conservative figure for a small diaphragm pump near its pressure limit.
- **Draining the mist line.** The line is a closed loop 70 mm inboard of the long beams and under the end beams, plus a down pipe to the drain valve: 11.91 m of 6.5 mm bore, holding 0.40 L. Through a 3 mm valve orifice at 0.5 m head it drains in about 30 s [C7], well inside R9's 5 min, but only if air can get in. Anti-drip nozzles close when the pressure drops, so the TRL 2 line would have held its water. A vacuum breaker at the front, highest point of the loop is added to BOM item 14.

## D. Droplets and wetting (R5)

A droplet stops being a wetting risk once it has evaporated. On the design day the air can take up 8.9 g/m³ more water vapor at the droplet surface, and on the humid edge only 3.8 g/m³ [D1]. The lifetime of a droplet grows with the square of its diameter and its fall distance with the fourth power, so size is everything:

*Table 2. Droplet lifetime and still-air fall [D2].*

| Diameter | Design day: life, fall | Humid edge: life, fall |
| --- | --- | --- |
| 30 µm | 0.48 s, 6 mm | 1.14 s, 15 mm |
| 50 µm | 1.34 s, 48 mm | 3.17 s, 114 mm |
| 80 µm | 3.44 s, 316 mm | 8.12 s, 745 mm |
| 100 µm | 5.38 s, 771 mm | 12.68 s, 1,819 mm |

Between the end of the jet under the rear nozzles and head height there are 759 mm. Droplets up to about 100 µm evaporate before reaching a head on the design day, and up to about 80 µm on the humid edge [D3]. R5 is therefore met only if the nozzle's droplet spectrum has nearly all its volume (Dv0.9) below about 80 µm at 7 bar. No maker's droplet data are in hand, so R5 cannot be judged at TRL 3. At 1 m/s wind, a 50 µm droplet drifts about 1.3 m before it is gone, and larger ones leave the canopy [D2]; this is the drift loss in the water balance.

## E. Cooling (R4, R3)

- **Heat absorbed.** Evaporation absorbs 9.40 kW averaged over the cycle and 18.8 kW while spraying; 6.90 kg/s of air crosses the zone at 1 m/s [E1].
- **Air temperature drop.** The drop is 1.35 °C averaged and 2.71 °C while spraying. The air takes 3 s to cross the canopy, less than one 20 s pulse, so people feel the pulses rather than the average [E2].
- **R4.** R4 is restated under CSH-DDR-002 as a drop of 2 °C or more while spraying. At the design day's 1 m/s the drop while spraying is 2.71 °C, and it stays at 2 °C or more in wind up to 1.35 m/s, so R4 is met. The former averaged target would have needed wind below 0.68 m/s; at 0.3 m/s the averaged drop would be 4.5 °C, but wetting risk rises in still air [E3].
- **Limits.** The design-day wet bulb is 23.0 °C, 15.0 °C below the air, so misting is far from saturating the air; it adds 0.56 g/kg of humidity [E4]. The design day absorbs about 47 kWh of heat [E5].
- **Radiant heat (R3).** CoolShade's main benefit remains the shade. The published figure for shade sails in Tempe is a 17.3 °C drop in mean radiant temperature ([Middel et al., 2021](https://journals.ametsoc.org/view/journals/bams/102/9/BAMS-D-20-0193.1.xml)). R3 is taken as met on that evidence, but it is unverified for this fabric, and a globe thermometer measurement is needed later.

## F. Energy (R8)

- **Use.** The pump takes 150 Wh, the controller and sensors 28.8 Wh and the normally open drain valve 25 Wh while held shut: 203.8 Wh per design day [F1].
- **Harvest and storage.** The panel yields 337.5 Wh, 1.66 times the use. The battery is now 12.8 V 25 Ah (CSH-DDR-002); its 256.0 Wh usable covers 1.256 design days without sun [F2]. With the former 20 Ah battery it was 204.8 Wh and 1.005 days, a margin of 1 Wh.
- **Latching valve option.** A latching drain valve would cut the use to 179.3 Wh and give 1.43 days with the 25 Ah battery, but a latching valve does not open by itself when power fails, so the line could sit full of warm water [F3]. The normally open valve is kept (CSH-DDR-002).
- **Currents.** Peak charge current is 7.4 A (the MPPT is rated 10 A) and the pump draws 4.7 A; the battery recharges from empty in 0.76 design days of sun [F4].
- **Heat.** The enclosure runs about 3.6 K above the air: 41.6 °C on the design day but 48.6 °C in 45 °C air. The battery stops charging above 45 °C, so charging stops whenever the air is above about 41.4 °C [F5]. On the hottest days the battery can only discharge; the design day (38 °C) is below that limit. R8 is met, with the hot-day charge limit noted.

## G. Structure and wind (R10)

- **Mass.** The steel weighs about 167 kg before bolts: four posts 79.9 kg (a front post 21.0 kg), braces 4.2 kg, long beams, end beams and panel bearer 35.1 kg, purlins 11.1 kg, base plates 15.2 kg, base cleats 11.9 kg, head and frame cleats 2.6 kg, and the equipment plate, enclosure rails and sensor arm 6.9 kg. The dead load on the anchors, with panel, rails, fabric, equipment and pump, is 167 kg (1.64 kN) [G1].
- **Wind.** A 30 m/s (108 km/h) gust gives 540 Pa, and with the fabric treated as solid, a normal force of 4.67 kN on the roof [G2].
- **Posts.** The horizontal load at roof level is 1.21 kN (the tilted roof, fabric friction and the roof edge) plus 86 N/m of drag on each post. As cantilevers with no help from the braces, the posts see 1.24 kN m each [G3], or 82 MPa with the 1.5 factor, a utilization of 0.30 of S275 [G4] (the posts are 13 mm longer at the front than in v0.2). The TRL 2 figure of about 144 MPa came from applying the whole normal force sideways; that is not a physical load case, but even that bound gives a utilization of 0.81 [G5].
- **Roof beams in bending.** If the long beams simply carry half the roof pressure over the 2.8 m post spacing, they reach a utilization of 0.70 [G6].
- **Fabric edge pull.** A tensioned fabric does not load the beams like a floor. It pulls inward on its edges with a force that grows as its sag shrinks. At 5 % sag the edge pull is 3.89 kN/m on each long beam, which bends the 50 x 50 x 2 mm beam sideways at a utilization of 3.52 [G7]. The beams can take 1.11 kN/m. To stay within that, the fabric would need 422 mm of sag (18 % of its span), or its porosity would need to relieve 72 % of the pressure, or it would have to come off above gusts of about 16 m/s (58 km/h) [G8].
- **Original R10 not met** on the conservative, solid-fabric case. Real knitted cloth is porous and stretches, both of which reduce the edge pull, but no data are in hand to show by how much. Amish accepted the recommendation to restate R10 (CSH-DDR-002): the frame and anchors must survive 30 m/s with the fabric removed, and the fabric is fitted only when forecast gusts are below 15 m/s (54 km/h). Removing the fabric before storms (decision D6) is therefore load-bearing, not a convenience.
- **Restated R10, fabric removed, 30 m/s.** The panel, as a flat plate of 0.67 m², takes 0.43 kN, 109 N at each of its four L-feet; the horizontal load at roof level is 0.33 kN; the post base moment is 0.60 kN m, a utilization of 0.14. The panel now stands at the rear edge on two feet on the panel bearer and two on the rear beam (CSH-DDR-003): the bearer reaches 0.02, the purlins carrying it 0.07 and the rear beam 0.11. The worst post lifts with 0.19 kN against 0.41 kN of dead load per post. Each anchor needs about 2.8 kN factored, mostly from the base moment [G13].
- **Rivet nuts.** Bolts into the closed beams go into M8 steel rivet nuts. The largest pull on one is about 0.16 kN factored, from the worst post's uplift shared by its two head cleat nuts or from one L-foot [G15]; the chosen rivet nut's pull-out rating in a 2 mm wall must be well above this, which is typical of steel rivet nuts but is to be confirmed from the maker's data.
- **Restated R10, fabric fitted, 15 m/s.** The pressure is 135 Pa, a quarter of the 30 m/s value. The fabric's edge pull brings the long beams to a utilization of 0.88 on the same solid-fabric, 5 % sag case; the posts are at 0.07 and each anchor needs about 1.5 kN factored [G14]. The restated R10 is met on paper; the anchors still depend on the slab at each site. A cord lacing that releases the fabric at a set load was recommended for study at TRL 4, which is on hold.
- **Anchors, original fabric-on 30 m/s case.** With the center of pressure 0.6 m off center, the worst post lifts with 1.76 kN, or 1.35 kN net of dead load and 2.27 kN factored [G9]. Adding the base moment over the 160 mm bolt pitch, each M16 anchor needs a factored tension of about 6.4 kN [G10]. Whether a given anchor in a given slab can provide it depends on the slab's thickness, concrete and edge distances, so the anchors cannot be verified at TRL 3. Under the restated R10 the governing anchor load falls to about 2.8 kN [G13]. Without anchors, 309 kg of ballast would be needed [G11], so anchoring stays mandatory.
- **Tank.** An empty 8 kg tank sees 163 N of drag; its overturning moment of 57 N m is well above the 21 N m that holds it down, so it would tip [G12]. A strap to the rear left post and two small anchors are added to BOM item 13.

## H. Handling (R17, R14)

The heaviest part is a front post at 21.0 kg (its brace now bolts on separately), against R17's 40 kg; a long beam weighs 9.0 kg and the panel 7 kg. A full tank weighs about 128 kg and must be drained before it is moved [H1]. The constructable design has 79 bolts and anchors, 36 of them M8 bolts into rivet nuts, and no welds [H2], so R14 is met by design; it needs two hand tools beyond R14's list (a rivet nut tool and a vice for the brace ends; open decision in CSH-DEC-001), and the 2-day build time cannot be checked on paper.

## I. Control, electrical and hygiene (R6, R12, R9)

- **Control.** A 10 s control loop with a 20 s debounce on the temperature and humidity conditions stops the spray within 30 s of a condition failing, inside R6's 60 s [I1]. The lag of the sensor in its radiation shield is not known.
- **Electrical.** The largest continuous battery current is 7.4 A while charging and 5.2 A while misting, so a 15 A terminal fuse has a margin of 2.0 [I2]. R12 is met by design.
- **Tank temperature.** On design days the tank water settles near the daily mean air temperature plus some solar gain, about 34 °C (with an assumed 26 °C night), inside the 20 to 50 °C range in which *Legionella* grows ([WHO](https://www.who.int/news-room/fact-sheets/detail/legionellosis)) [I3]. R9 stays at risk: the design controls water age (under 24 h with the routine) and line draining (about 27 s), but not temperature.

## J. Cost (R13)

The BOM has 16 lines, all priced, totaling an estimated $882.00 against the $775 value-engineering target (`budget_usd`, set on 2026-09-25 under CSH-DDR-002; a hypothetical control target, not a limit): $107.00 (13.8 %) over [J1]. The concept came to $773.00; the parts added to make it buildable (CSH-DDR-003: cleats, rivet nuts, panel bearer and mounting kit, base cleats, equipment plate, enclosure rails, sensor arm, line clips, tank level switch, I2C extender, cloth notch and more fixings) add $109. The steel lines (1, 2 and 4) come to $269 for about 167 kg, about $1.61/kg including cutting, drilling and galvanizing, which still looks low for small quantities [J2]. R13 is over the value-engineering target by $107; savings worth trying are in CSH-DEC-001. `budget_usd` is not changed.

## K. Results against every requirement

*Table 3. Requirement status from this note.*

| ID | Requirement | Value | Target | Status |
| --- | --- | --- | --- | --- |
| R13 | Cost | $882 [J1] | $775 or less (value-engineering target) | **Over the value-engineering target by $107** (13.8 %) after the parts added for construction |
| R9 | Water hygiene | Water under 24 h old with the routine [C5]; line drains in about 30 s [C7]; tank about 34 °C [I3] | Age 48 h or less; drained within 5 min | At risk: water sits in the *Legionella* growth range |
| R16 | Maintenance | Scaling of 0.4 mm orifices | Descaling interval 1 month or more | At risk; not verifiable at TRL 3 |
| R5 | No wetting | Needs Dv0.9 below about 80 µm at 7 bar [D3] | No wetting at 1.5 m | Not verifiable at TRL 3 (no droplet data) |
| R4 | Air cooling from misting | 2.71 °C while spraying (1.35 °C averaged) at 1 m/s [E2] | 2 °C or more while spraying (restated) | Met; holds to 1.35 m/s [E3] |
| R8 | Energy autonomy | 203.8 Wh used, 337.5 Wh harvested; 25 Ah battery 1.256 days [F2] | Energy-neutral; 1 day without sun | Met; no charging above about 41 °C air [F5] |
| R10 | Wind resistance | Fabric off at 30 m/s: posts 0.14, bearer 0.02, purlins 0.07 [G13]; fabric on at 15 m/s: long beams 0.88 [G14]; anchors about 2.8 kN each | Restated: survive 30 m/s with fabric removed; fabric on only below 15 m/s | Met on paper; anchors to be confirmed per site. Original fabric-on case: beams 3.52 [G7] |
| R1 | Shaded waiting area | 6.30 m² or more shadow above 45° sun [A2]; 8 standing + 3 seated + wheelchair [A3] | 6 m²; 6 people and a wheelchair | Met |
| R2 | Headroom | 2,223 mm at the rear braces' flattened ends [B2] | 2,200 mm or more | Met |
| R3 | Radiant heat reduction | About 17.3 °C for shade sails (literature) | 15 °C or more | Met on published evidence; unverified for this fabric |
| R6 | Smart activation | Stop within 30 s [I1] | Within 60 s | Met by design |
| R7 | Water use | 85 L used, 95 L drawn [C2], [C5] | 100 L or less | Met at 4 L/h per nozzle; at risk above 4.75 L/h [C3] |
| R11 | Privacy | PIR only, no link fitted | No camera or microphone | Met by design |
| R12 | Electrical safety | 12 V DC, 15 A fuse, margin 2.0 [I2] | 12 V, fused, IP65, BMS | Met by design |
| R14 | Buildability | Bolted, 79 fasteners [H2] | No welding; 2 days | Met by design; rivet nut tool and bench vice in R14 since 2026-10-02; time unverified |
| R15 | Refill interval | 1.41 design days [C4] | 1 day or more | Met |
| R17 | Movability | Heaviest part 21.0 kg [H1] | 40 kg or less | Met |

In summary: 1 over its value-engineering target (R13), 2 at risk (R9, R16), 1 not verifiable at TRL 3 (R5) and 13 met (R1, R2, R3, R4, R6, R7, R8, R10, R11, R12, R14, R15, R17). In v0.2, before CSH-DDR-003, R13 was at risk ($773 against $775). In v0.1, before CSH-DDR-002, the count was 3 not met (R4, R10, R13), 3 at risk (R8, R9, R16), 1 not verifiable and 10 met.

## Checks against the TRL 2 figures

- Water (85 L), tank endurance (1.4 days), energy use (about 205 Wh), harvest (about 340 Wh), battery (about 205 Wh) and cooling (1.4 °C averaged and 2.7 °C while spraying) all stand.
- Parts cost rises from about $735 to $758 at TRL 3, and to $773 with the 25 Ah battery (v0.2).
- The post stress of about 144 MPa at TRL 2 was an upper bound; the physical case gives 54 MPa unfactored. R10 moves from "unverified" to "not met" because of the fabric edge pull, which the TRL 2 estimate did not consider.
- Headroom under the rear braces rises from about 2.1 m to 2,234 mm, so R2 is now met with margin.
- The TRL 2 structure mass of about 130 kg becomes about 143 kg of steel before brackets and bolts.
- v0.3 (constructable design, CSH-DDR-003): steel 167 kg with cleats and plates, headroom 2,223 mm, mist line 11.91 m, parts $882.

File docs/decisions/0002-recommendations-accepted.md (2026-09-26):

---
doc_id: CSH-DDR-002
title: CoolShade recommendations accepted
project: CoolShade
doc_type: Design decision record
version: "0.1"
status: Draft
date: '2026-09-25'
author: Amish Chadha
license: CERN-OHL-S-2.0
revisions:
- version: "0.1"
  date: '2026-09-25'
  author: Amish Chadha
  change: Recommendations accepted by Amish (DDR-002); record every newly decided item, what changed in the repo and the items still open
---
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

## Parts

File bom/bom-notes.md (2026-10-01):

# BOM notes

Costs are indicative USD prices for a single prototype, estimated in September 2026 without supplier quotes. Every line is priced and has a supplier type. Line numbers match the exploded view (`media/exploded.png`) and the component table in the design precis (CSH-PRC-001). Line 16 has no callout.

- Parts total: an estimated $882.00, against the $775 value-engineering target (`budget_usd` in `project.yaml`, a hypothetical control target; $107.00, 13.8 %, over). The target was set at $775 on 2026-09-25 (CSH-DDR-002; it was $700). `budget_usd` is not changed; savings worth trying are in CSH-DEC-001. See CSH-CAL-001, section J.
- Design for construction (CSH-DDR-003, 2026-09-30), +$109: cleats, rivet nuts, end caps and panel bearer (line 2, +$15); cloth notch (line 3, +$3); base cleats (line 4, +$24); panel mounting kit (line 5, +$20); enclosure rails and battery straps (line 8, +$3); sensor arm and I2C extender (line 9, +$8); equipment plate (line 10, +$6); line clips and longer line (line 12, +$5); tank level switch and stop cleats (line 13, +$7); fixings (line 16, +$18).
- TRL 3 changes: the mist line is now a closed loop of about 11 m (line 12, +$5); the tank has a strap and two small anchors (line 13, +$10); a vacuum breaker lets the line drain past its anti-drip nozzles (line 14, +$8).
- Recommendations accepted (CSH-DDR-002): the battery is 25 Ah instead of 20 Ah for energy margin (line 6, +$15).
- The steel lines (1, 2 and 4) come to about $1.61/kg for about 167 kg including cutting, drilling and galvanizing, which looks low for small quantities. Cost is at risk of rising until quoted.
- Not included: site survey, permits, an engineer's check of the slab and anchors, concrete footings where no slab exists, the existing bench, water, and labor.
- Items 6 and 7 sit inside the equipment enclosure (item 8).

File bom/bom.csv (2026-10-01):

item | qty | spec | supplier | unit_cost_usd | make_buy | notes
1 Posts with knee braces | 4 | 80 x 80 x 3 mm hot-dip galvanized steel square hollow section: two front posts 2.90 m and two rear posts 2.61 m; one knee brace each from 32 mm galvanized tube, 0.58 m, both ends flattened and bent 45 degrees; bolted, no welding | Local steel stockist | 30.00 | buy | Indicative price per post with brace; brace ends flattened in a vice (CSH-DDR-003)
2 Roof frame | 1 | 50 x 50 x 2 mm galvanized SHS: two 3.00 m long beams, two 2.32 m end beams and a 1.02 m panel bearer; two 40 x 40 x 2 mm purlins 2.32 m; 8 head cleats (46 mm) and 10 frame cleats (30 or 40 mm) cut from 50 x 50 x 5 mm angle; 36 M8 and 20 M5 steel rivet nuts; plastic end caps; about 7 degree mono-pitch | Local steel stockist | 85.00 | buy | Indicative price; cleats, bearer and rivet nuts added for construction (CSH-DDR-003)
3 Shade fabric | 1 | Knitted HDPE shade cloth, about 90 % UV block, 3.0 x 2.4 m with a 1.02 x 0.665 m notch at the rear centre for the solar panel; reinforced hem and eyelets all round, including the notch; laced over the frame with cord | Shade sail or agricultural supplier | 48.00 | buy | Indicative price, made to size; removable, fitted only in forecast gusts below 15 m/s (CSH-DDR-002); notch added (CSH-DDR-003)
4 Base plates and anchors | 4 | Per post: 220 x 220 x 10 mm steel base plate and two base cleats of 75 x 75 x 6 mm galvanized angle, 220 mm long, with four M16 expansion or chemical anchors through cleats and plate into an existing concrete slab | Local fabricator and hardware shop | 16.00 | make | Indicative price per set; base cleats added (CSH-DDR-003); footing adequacy to be checked at each site
5 Solar panel | 1 | 100 W monocrystalline, about 1,000 x 670 x 35 mm, Vmp about 18 V; mounting kit of two aluminium rails 0.77 m, four L-feet and four end clamps | Regional solar distributor | 80.00 | buy | Indicative price; rails stand on L-feet on the panel bearer and the rear beam (CSH-DDR-003)
6 LiFePO4 battery | 1 | 12.8 V 25 Ah (about 320 Wh) with built-in BMS and low-temperature charge cutoff, fused at the terminal | Battery distributor | 100.00 | buy | Indicative price; inside item 8; 25 Ah instead of 20 Ah for energy margin (CSH-DDR-002)
7 MPPT charge controller | 1 | 12 V, 10 A MPPT with LiFePO4 profile and load output | Solar distributor | 25.00 | buy | Indicative price; inside item 8
8 Controller and enclosure | 1 | Lockable IP65 steel or polycarbonate enclosure about 420 x 320 x 160 mm with moulded mounting holes outside the gasket and internal bosses for a gear plate; microcontroller board, MOSFET pump driver, valve driver, blade fuses, tamper-proof screws, three M20 cable glands; two battery hold-down straps; two 40 x 6 mm steel rails 340 mm long | Electronics distributor | 38.00 | buy | Indicative price; rails added (CSH-DDR-003); firmware not started (TRL 4 scope)
9 Sensor head | 1 | Digital temperature and humidity sensor (SHT4x class) in a multi-plate radiation shield with a top mounting plate, with an I2C bus extender pair for its 7 m cable, on a 375 mm arm of 40 x 40 x 4 mm galvanized angle; passive infrared presence sensor with a small bracket under the front beam; no camera or microphone | Electronics distributor | 38.00 | buy | Indicative price; arm made from angle and I2C extender added (CSH-DDR-003)
10 Misting pump | 1 | 12 V DC diaphragm pump, about 7 bar (100 psi) with pressure switch, about 60 W, in a small vented box; mounted with the filter and drain valve on a 320 x 630 x 3 mm galvanized steel equipment plate bolted to the rear left post | Misting or RV pump supplier | 61.00 | buy | Indicative price; equipment plate added (CSH-DDR-003)
11 Filter and check valve | 1 | 5 um sediment cartridge filter in a clear housing, inlet strainer and check valve | Plumbing supplier | 20.00 | buy | Indicative price
12 Mist line and nozzles | 1 | About 12 m of 9.5 mm (3/8 in) nylon or stainless misting line (6.5 mm bore) laid as a closed loop 70 mm inboard of the long beams and under the end beams, with slip-lok tees and elbows; 8 brass low-pressure nozzles with anti-drip check valves, about 0.4 mm orifice; 18 hanger clips | Misting supplier | 50.00 | buy | Indicative price; loop length from cad/src/model.py; nozzle flow to confirm from the maker's data (CSH-CAL-001)
13 Water tank | 1 | 120 L opaque, food-grade polyethylene, lockable lid, bottom outlet; low-level float switch with 9 m cable; ratchet strap round the tank and the rear left post; two stop cleats of 50 x 50 x 5 mm angle, each with an M10 anchor to the slab; optional float valve for a mains connection with a backflow preventer | Local plastics or farm supplier | 72.00 | buy | Indicative price; strap because an empty tank can tip in a 30 m/s gust (CSH-CAL-001); mains connection optional and subject to local water rules; level switch added, needed for R6 (CSH-DDR-003)
14 Drain valve and vacuum breaker | 1 | 12 V normally open solenoid drain valve (about 3 mm orifice) at the bottom of the down pipe, opens when the pump stops; air admittance valve (vacuum breaker) on a tee in the front run, the highest part of the mist line loop, so the line can drain past the anti-drip nozzles | Irrigation supplier | 23.00 | buy | Indicative price; vacuum breaker added at TRL 3 (CSH-CAL-001)
15 Hose and wiring harness | 1 | Pump suction and delivery hose, UV-stable outdoor cable run inside the posts and beams, rubber grommets, cable glands | Hardware and electrical shop | 20.00 | buy | Indicative price
16 Hardware and consumables | 1 | Fixings, galvanized or stainless: 8 M12 x 110 and 8 M10 x 100 through bolts with nyloc nuts; 36 M8 x 16 bolts into rivet nuts; 4 M10 countersunk bolts (enclosure rails); 3 M8 bolts (sensor arm); 2 M10 bolts (equipment plate); M6 and M5 screws; washers; lacing cord, cable ties, thread sealant, zinc-rich touch-up paint | Local hardware shop | 38.00 | buy | Indicative price; no exploded-view callout

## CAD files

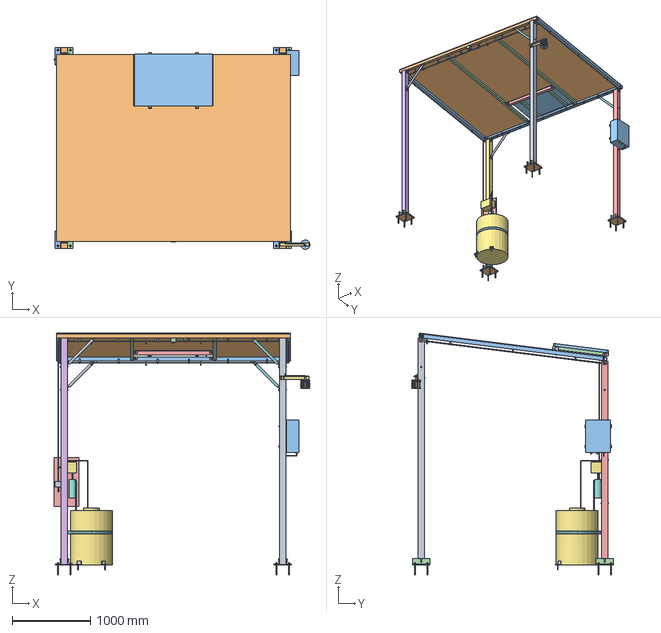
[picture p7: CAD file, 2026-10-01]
cad/step/coolshade-assembly.step
3280.0 x 2583.6 x 3097.5 mm

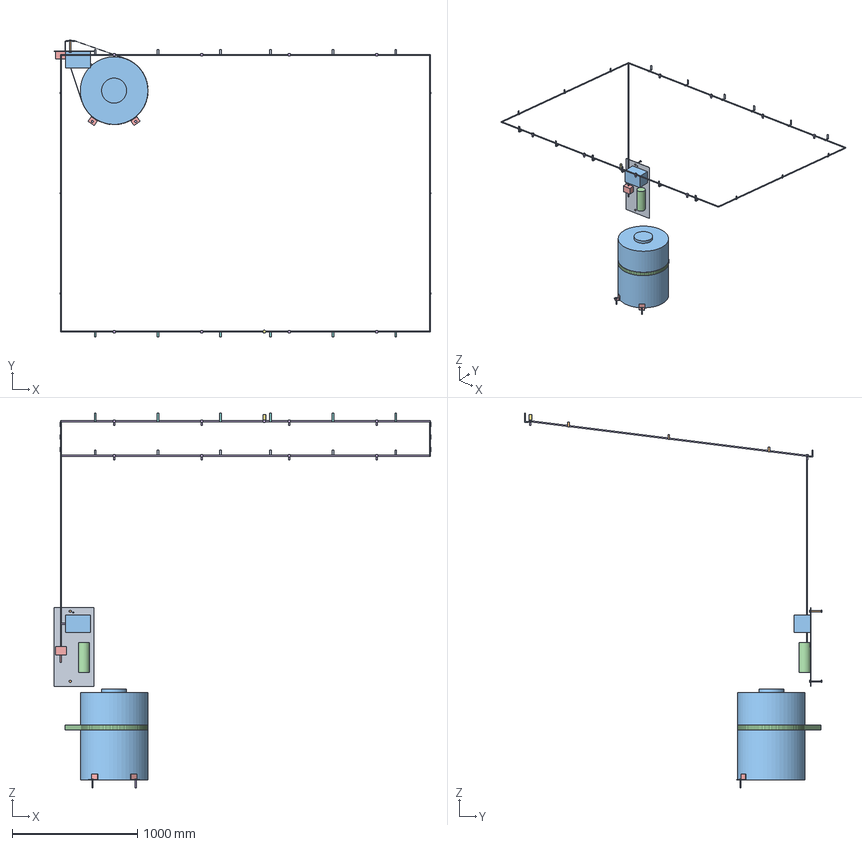
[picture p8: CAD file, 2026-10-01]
cad/step/water-system.step
3011.8 x 2376.0 x 2991.9 mm

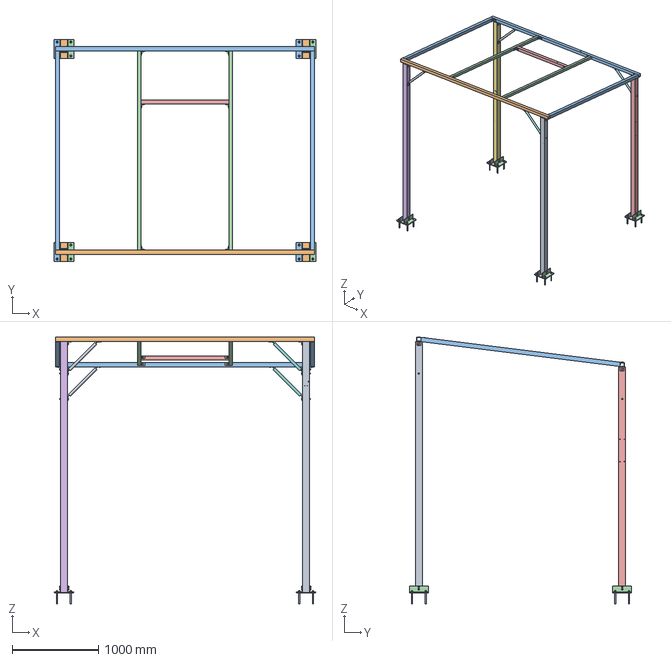
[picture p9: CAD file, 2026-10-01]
cad/step/frame.step
3030.0 x 2570.0 x 3086.9 mm

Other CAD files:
cad/stl/coolshade-assembly.stl
cad/stl/frame.stl
cad/stl/water-system.stl

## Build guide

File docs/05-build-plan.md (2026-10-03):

---
doc_id: CSH-BLD-001
title: CoolShade prototype build plan
project: CoolShade
doc_type: Build plan
version: "0.3"
status: Draft
date: '2026-10-02'
author: Amish Chadha
license: CERN-OHL-S-2.0
revisions:
  - version: "0.1"
    date: '2026-09-30'
    author: Amish Chadha
    change: First build plan at TRL 3, with pictures by component and step; design made constructable (CSH-DDR-003)
  - version: "0.2"
    date: '2026-10-02'
    author: Amish Chadha
    change: "Section 2: the changes recorded in CSH-DDR-003 accepted by Amish on 2026-10-02"
  - version: "0.3"
    date: '2026-10-02'
    author: Amish Chadha
    change: "Safety stops S7 and S9 name the market operator's manager and the environmental health authority for a market lane"
---

# CoolShade prototype build plan

**Plan, not yet built.** How to build the first proof-of-concept prototype, component by component. Building and testing to it is TRL 4 work. Decisions still to be made are kept in the design decisions register ([docs/06-design-decisions.md](06-design-decisions.md)), not here.

## 1. What you are building

Figure 1. Every component, pulled apart and numbered in build order

*Figure 1. Every component pulled apart and numbered in build order. The cables, which run inside the posts and beams, are not shown.*

The prototype is one CoolShade canopy on an existing concrete slab: four 80 mm square steel posts on a 2,800 x 2,350 mm grid carry two horizontal long beams, and between them two sloping end beams, two purlins and a panel bearer make a roof frame 3.0 x 2.4 m in plan that falls 300 mm from the street edge to the rear. Knitted shade cloth is laced over the frame; a 100 W solar panel sits in a notch at the rear of the cloth on two rails. A mist line loop with eight nozzles hangs under the roof; the pump, filter and drain valve are on a plate on the rear left post, the 120 L tank is strapped beside it, and the controller, battery and charge controller are in a locked box on the rear right post. Figure 1 shows the 21 components in the order you make or fit them. Fourteen kinds of part are made in a workshop from steel tube, angle, flat bar, plate and sheet by sawing, drilling, flattening and bending; everything else is bought and fitted. There is no welding: every joint is bolted, and bolts into the closed beams go into rivet nuts. The parts cost about $882 from the bill of materials.

> **Safety:** This is a wind-loaded steel structure built at height, with a 12.8 V lithium iron phosphate battery of about 320 Wh and a water line at about 7 bar that sprays an aerosol near the public. Lift posts and beams with two people, work from stable ladders or a platform, keep the battery fuse out and the line unpressurized until section 6 allows, use potable water only, and fit the cloth only when forecast gusts are below 15 m/s (54 km/h). Cut steel edges and flattened tube ends are sharp: deburr them and wear gloves.

## 2. What changed to make it buildable

The concept showed what CoolShade does; most of its parts met as overlapping blocks with no fixing. Each change below keeps what the canopy does, and all of them are recorded in decision record CSH-DDR-003, accepted by Amish on 2026-10-02.

*Table 1. Changes from the concept.*

| Component | The concept had | The buildable design has | Why |
| --- | --- | --- | --- |
| Post grid and long beams | Posts 2,100 mm apart across the sidewalk; the cloth ran 125 mm past the beams with nothing under its edges | Posts 2,350 mm apart; the long beams sit on the post tops at the roof's street and rear edges (Figures 2 and 10) | Every edge of the cloth has a tube to lace to; the clear floor widens to 2.27 m |
| Roof corners | Beams overlapping each other and the post tops, tilted with the roof | Long beams horizontal on the posts; end beams, purlins and bearer cut to butt against the beam faces on angle cleats (Figures 17 and 18) | Face-to-face bolted joints a square tube can make |
| Post top and base | No fixing to the beam or the base plate | Head cleats (Figure 10) and base cleats (Figure 5), all bolted | No welding (R14) |
| Knee braces | Solid rods running into the post and beam | Tube with flattened, bent ends bolted flat to the post and beam (Figures 22 and 30) | The simplest bolted brace; its lowest point is 2,223 mm, above the 2,200 mm headroom (R2) |
| Solar panel | On rails floating above the purlins, on top of the cloth | At the rear edge on rails and L-feet on a new panel bearer and the rear beam; the cloth has a notch under it (Figures 22 and 30) | The cloth comes off before storms without touching the panel |
| Enclosure, sensor head, PIR | Floating beside the posts and beams | Enclosure rails, an angle sensor arm at 2.4 m, a PIR bracket (Figures 31 and 32) | Each is bolted, and the shield hangs 2,266 mm up |
| Pump, filter, drain valve | Floating beside the rear left post, no pipe to the drain valve | On an equipment plate; the down pipe ends in the drain valve (Figure 33) | One plate, and the valve stays at the low point |
| Tank | Overlapping the post base | Moved clear, strapped to the post, with two stop cleats (Figure 35) | It cannot tip or slide |
| Cables and missing parts | Cables through walls; no tank level switch | Cables inside the posts and beams; a tank level switch and an I2C extender added (step 16) | The control rules need the level switch; the sensor cable is about 7 m |

## 3. Making the components

Make and check each component before the assembly step that needs it. Sizes are in millimetres. "Left" and "right" are as seen standing on the street side looking at the canopy; "inner" faces face the middle of the canopy. Workshop tolerance is 1 mm unless a step says otherwise; drawings carry no tolerances before TRL 4. Galvanized steel is drilled after galvanizing here: paint every cut end, hole and flattened end with zinc-rich paint.

### 3.1 Base plates (make 4)

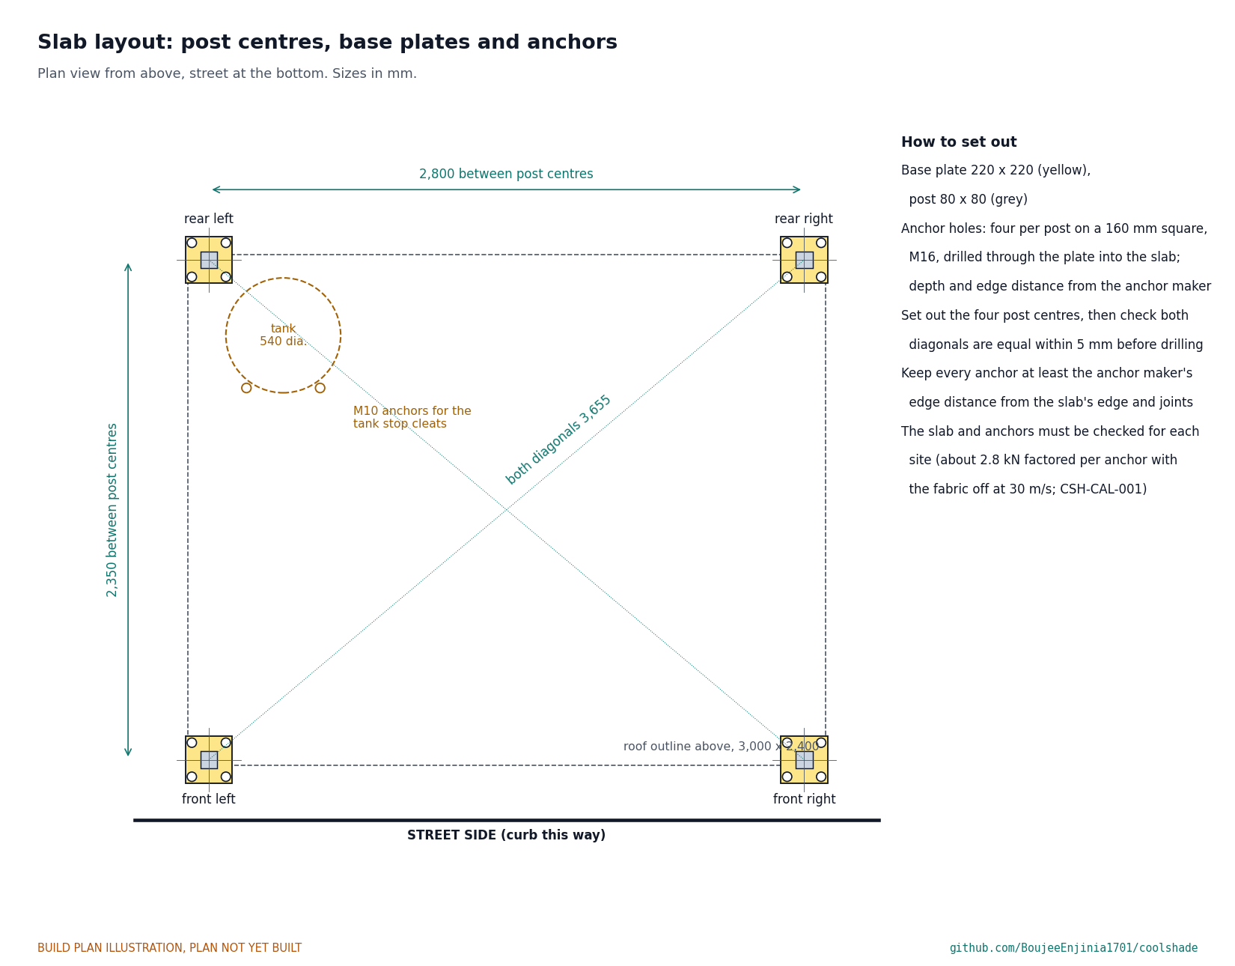
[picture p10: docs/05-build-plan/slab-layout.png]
Figure 2. Slab layout


*Figure 2. Slab layout: post centres, base plates and anchor holes.*

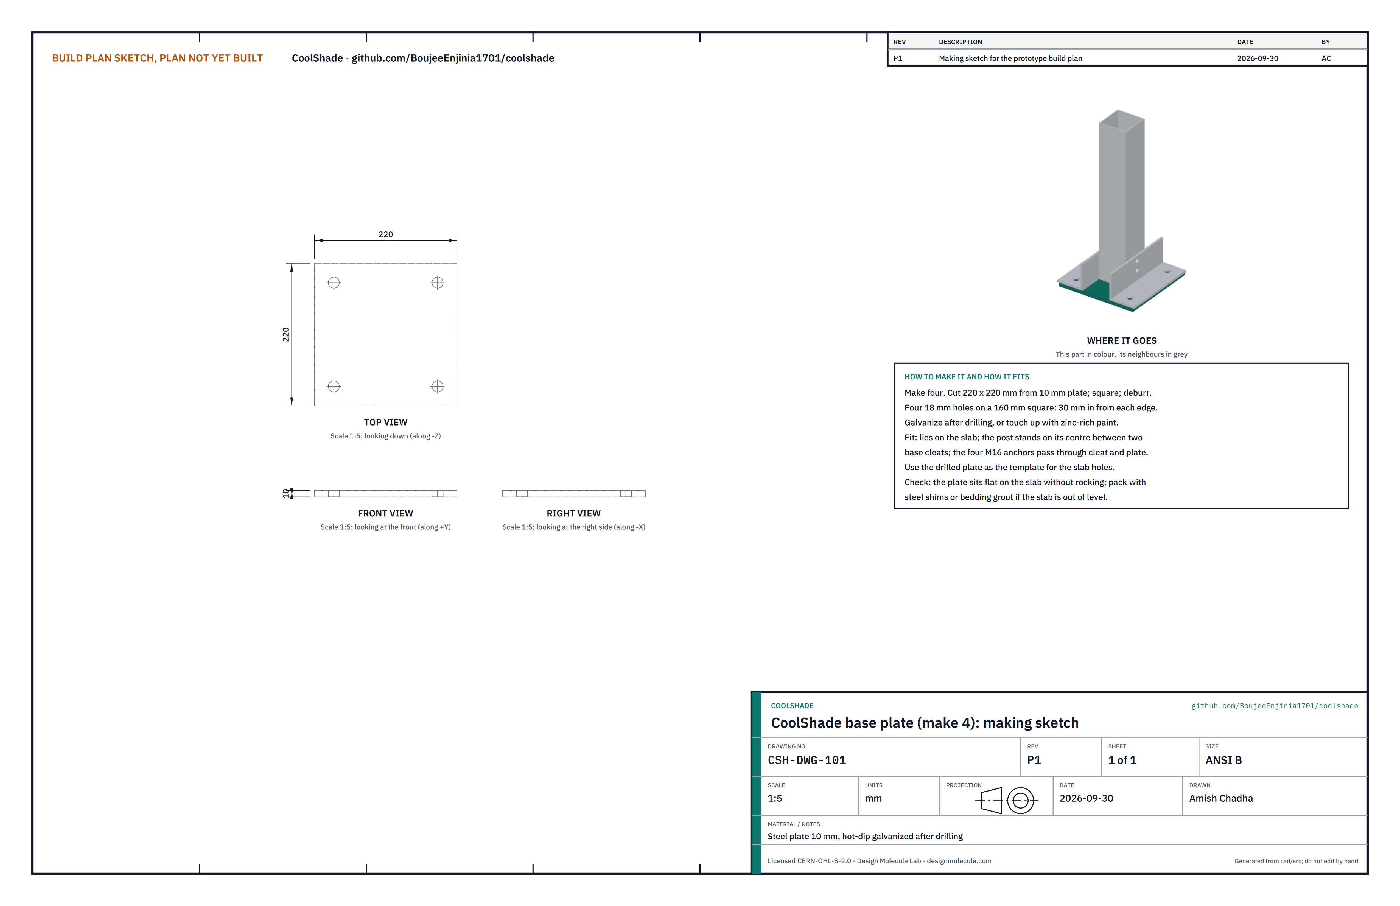
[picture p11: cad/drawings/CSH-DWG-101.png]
Figure 3. Making sketch of the base plate


*Figure 3. Base plate making sketch (CSH-DWG-101).*

**What it is and what it is made from.** The square plate each post stands on, anchored to the slab. Steel plate 10 mm thick.

**How to make it.**

1. Cut four plates 220 x 220 mm; deburr.
2. Drill four 18 mm holes on a 160 mm square, 30 mm in from each edge.
3. Zinc-rich paint, or galvanize the plates after drilling.

**How it fits the parts next to it.** It lies flat on the slab; the post stands on its centre between two base cleats, and four M16 anchors pass through the cleats and the plate into the slab (Figure 5). The drilled plate is the template for the slab holes.

**Check before moving on.** Each plate sits flat on the slab where Figure 2 puts it without rocking; if not, pack it with steel shims or bed it on grout.

### 3.2 Base cleats (make 8)

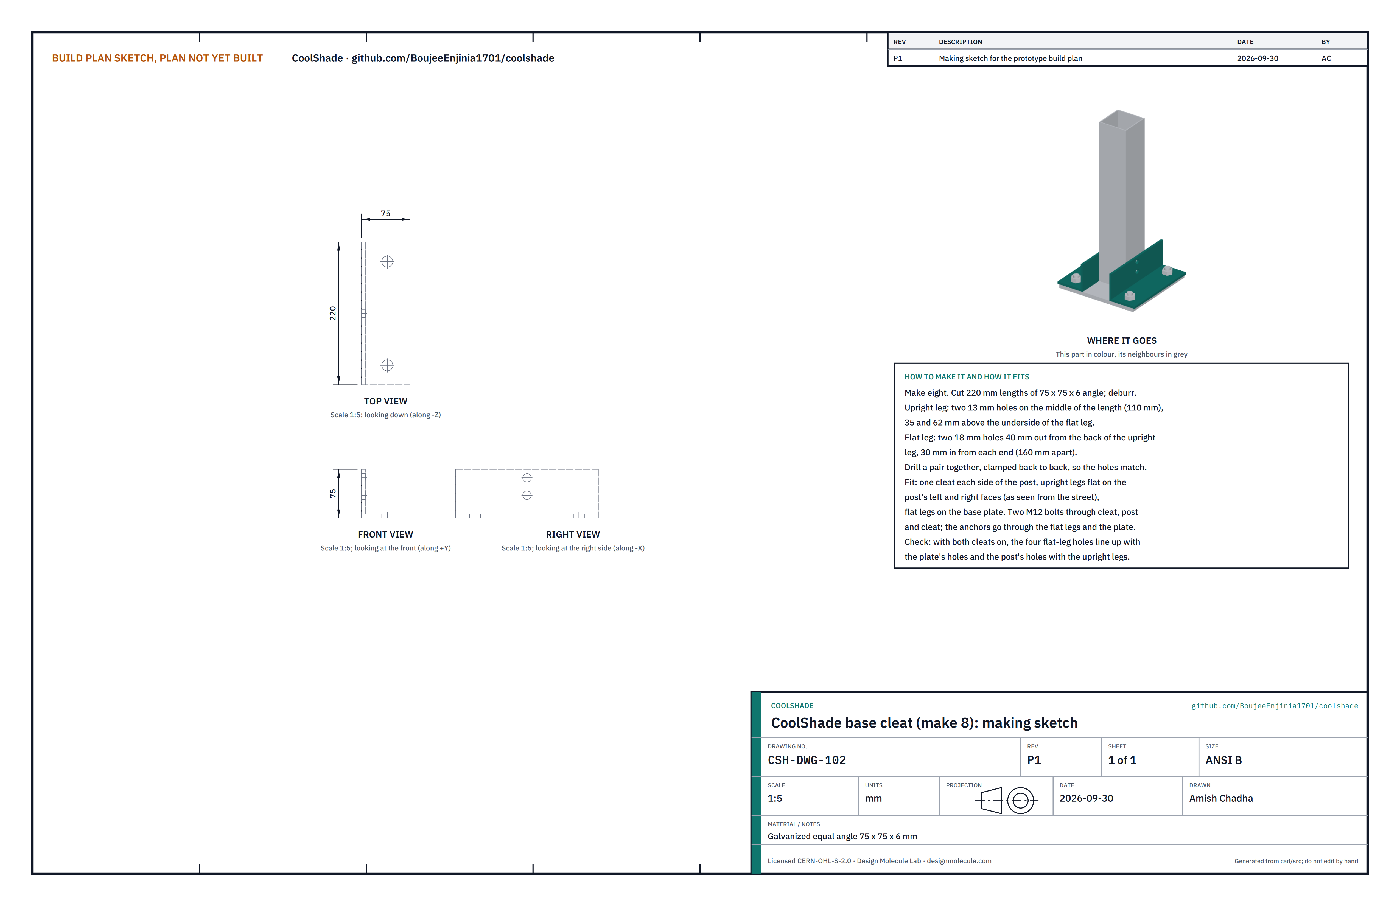
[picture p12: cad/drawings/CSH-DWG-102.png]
Figure 4. Making sketch of the base cleat


*Figure 4. Base cleat making sketch (CSH-DWG-102).*

**What it is and what it is made from.** A short angle each side of the post's foot that bolts the post to the plate and slab. Galvanized equal angle 75 x 75 x 6 mm.

**How to make it.**

1. Cut eight 220 mm lengths; deburr.
2. Upright leg: two 13 mm holes at mid-length, 35 and 62 mm above the underside of the flat leg.
3. Flat leg: two 18 mm holes 40 mm out from the back of the upright leg and 30 mm in from each end, 160 mm apart.
4. Drill the cleats in pairs, clamped back to back, so the holes match.

**How it fits the parts next to it.**

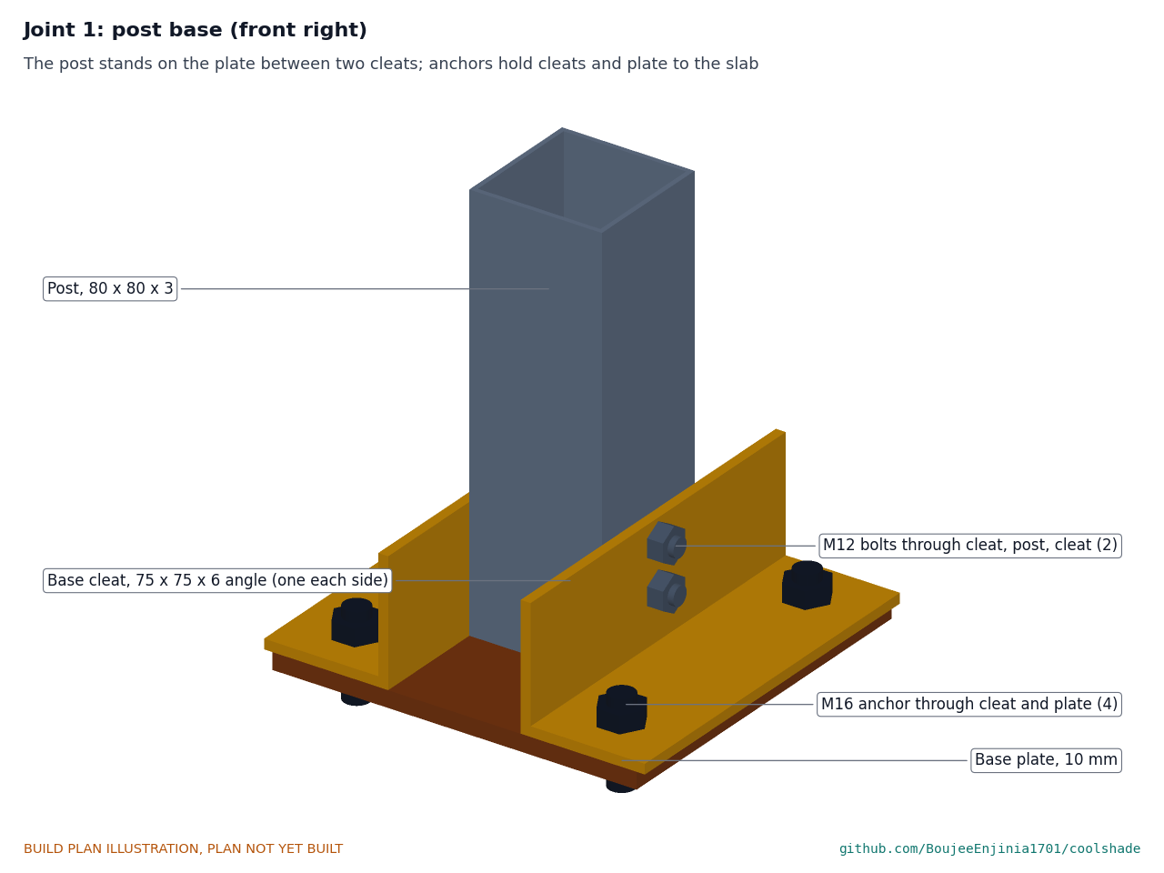
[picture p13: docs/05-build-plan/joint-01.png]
Figure 5. Joint 1: post base


*Figure 5. The post stands on the plate between two cleats; two M12 bolts go through cleat, post and cleat; the anchors pass through the cleats' flat legs and the plate.*

The cleats go on the post's left and right faces, upright legs flat on the post, flat legs flat on the plate, flat legs pointing away from the post. The two M12 bolts are tightened only after the post is plumb (step 2).

**Check before moving on.** On a trial fit with a post offcut, the four flat-leg holes line up with the plate's and the upright-leg holes with the post's.

### 3.3 Posts (make 4: two front, two rear)

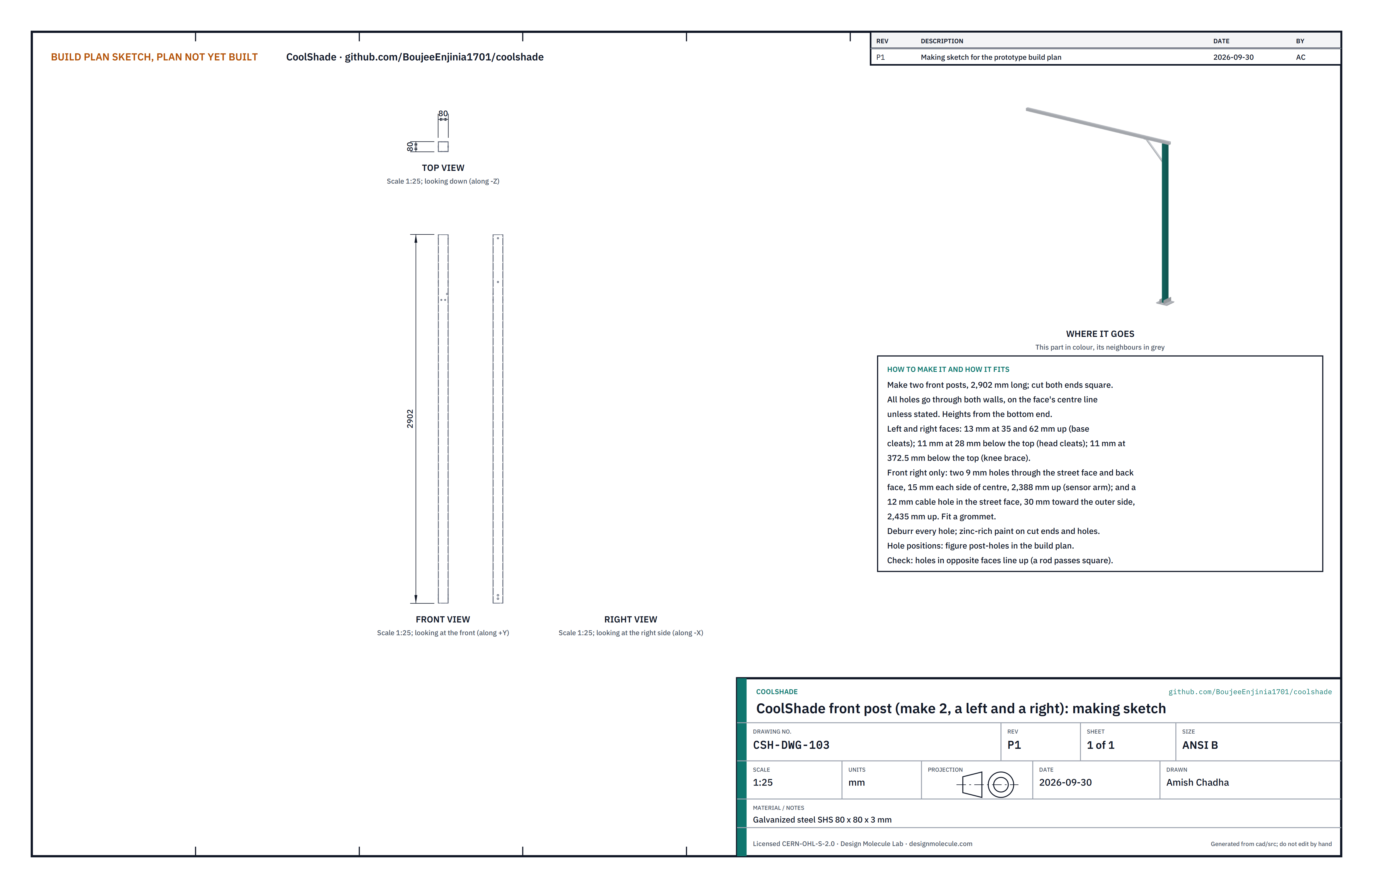
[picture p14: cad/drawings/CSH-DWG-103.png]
Figure 6. Making sketch of the front post


*Figure 6. Front post making sketch (CSH-DWG-103).*

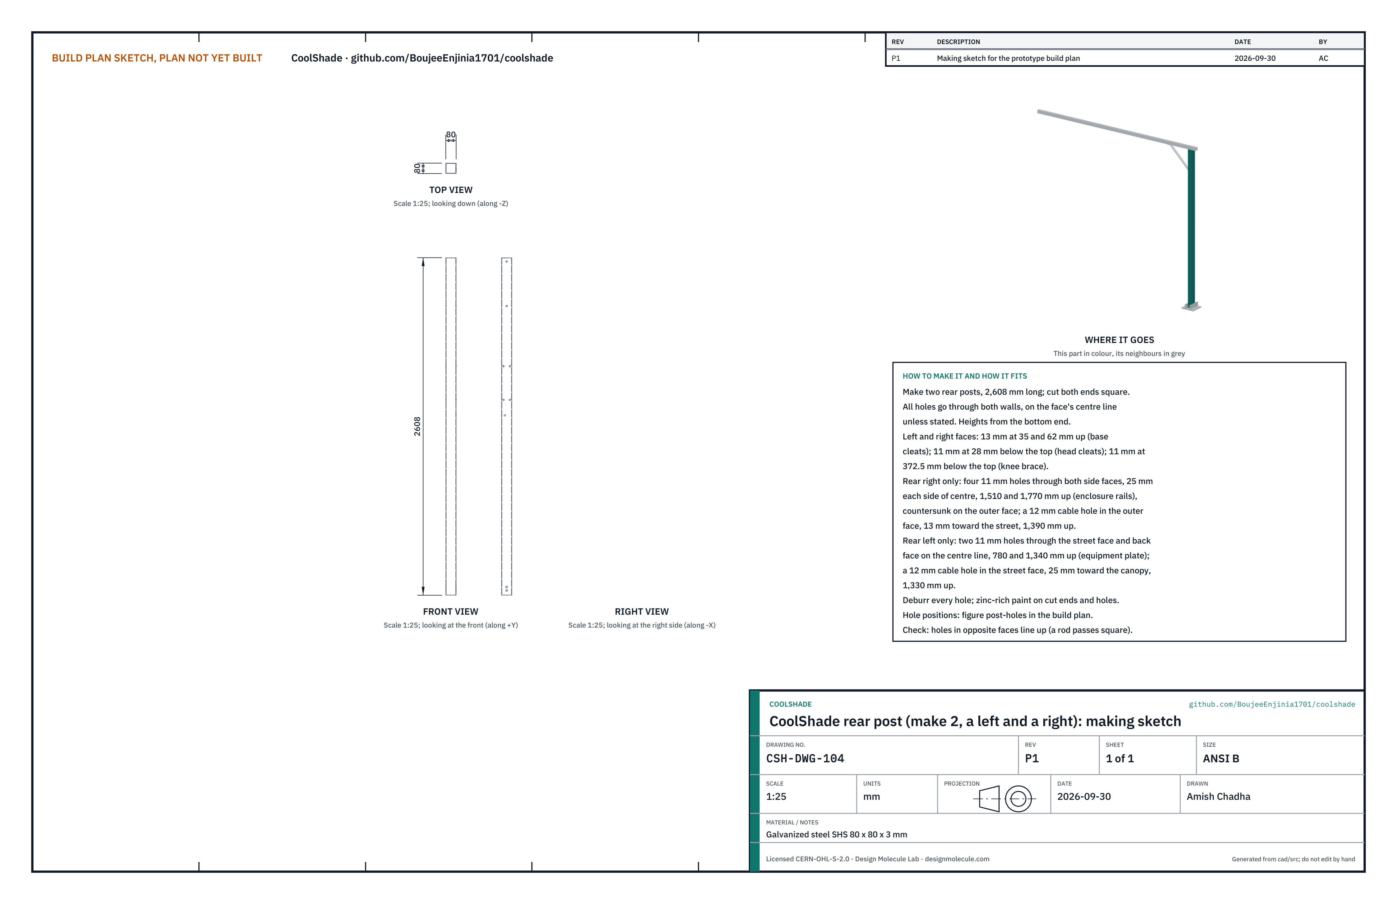
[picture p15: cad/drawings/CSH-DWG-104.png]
Figure 7. Making sketch of the rear post


*Figure 7. Rear post making sketch (CSH-DWG-104).*

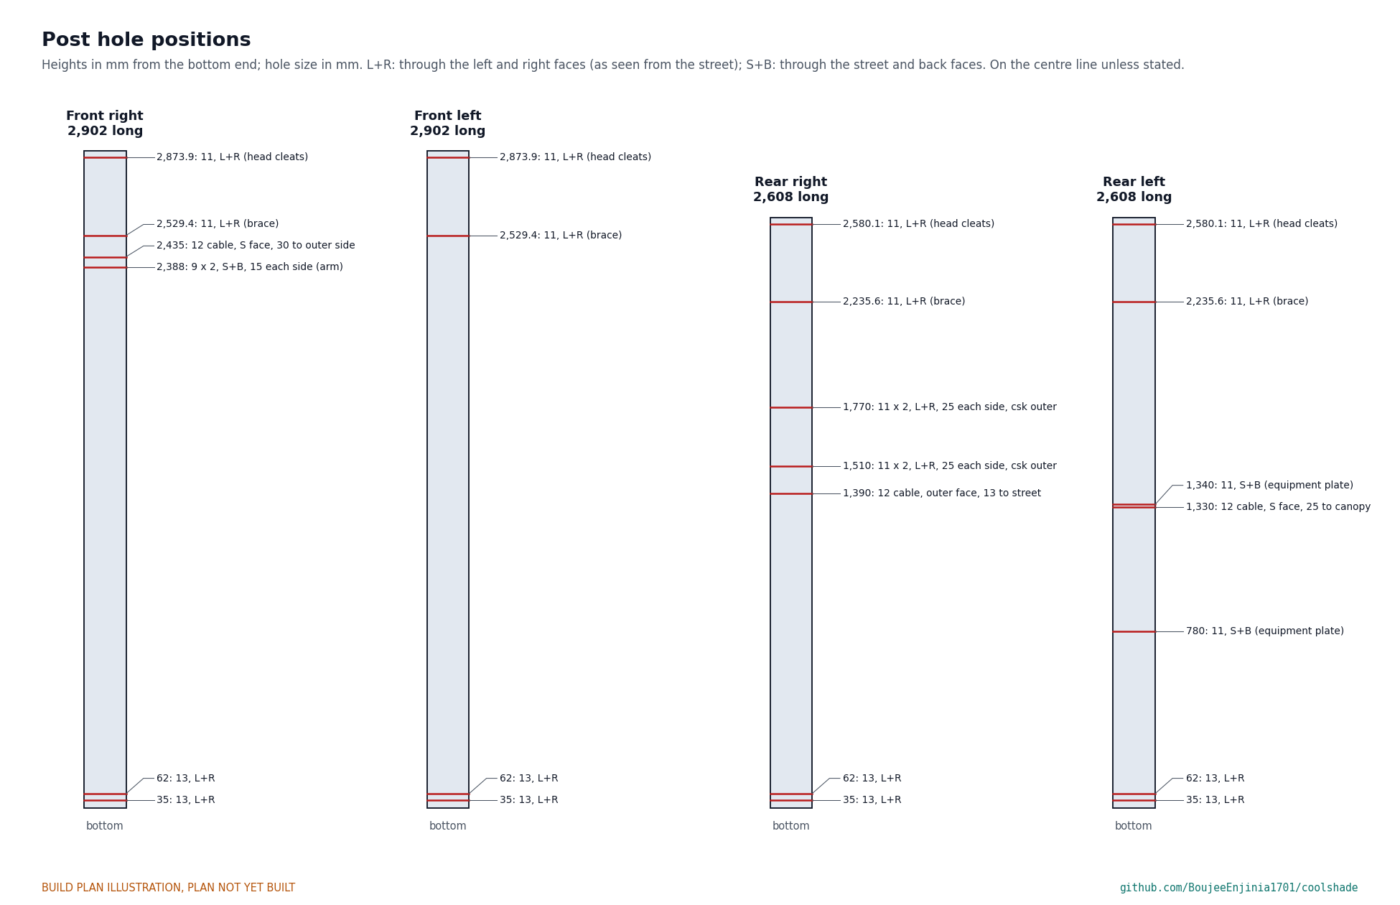
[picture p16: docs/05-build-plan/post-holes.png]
Figure 8. Post hole positions


*Figure 8. Every post hole, measured up from the bottom end.*

**What it is and what it is made from.** The four legs. Galvanized steel square hollow section 80 x 80 x 3 mm: two front posts 2,902 mm long and two rear posts 2,608 mm long, the difference making the roof's fall.

**How to make it.**

1. Cut the four posts to length with both ends square; the top end must be square so the beam sits flat on it.
2. Drill the holes every post has, through both walls of its left and right faces, on the centre line: 13 mm at 35 and 62 mm from the bottom (base cleats), 11 mm at 372.5 mm below the top (knee brace) and 11 mm at 28 mm below the top (head cleats).
3. Drill the extra holes each post has, from Figure 8:
   - front right: two 9 mm holes through the street and back faces, 15 mm each side of centre, 2,388 mm up (sensor arm); a 12 mm cable hole in the street face, 30 mm toward the outer side, 2,435 mm up;
   - rear right: four 11 mm holes through the left and right faces, 25 mm each side of centre, 1,510 and 1,770 mm up, countersunk on the outer face (enclosure rails); a 12 mm cable hole in the outer face, 13 mm toward the street, 1,390 mm up;
   - rear left: two 11 mm holes through the street and back faces on the centre line, 780 and 1,340 mm up (equipment plate); a 12 mm cable hole in the street face, 25 mm toward the canopy, 1,330 mm up.
4. Deburr, paint the cut ends and holes, and fit a rubber grommet in each cable hole.

**How it fits the parts next to it.** The bottom stands on the base plate between the base cleats (Figure 5); the top carries the long beam and two head cleats (Figure 10); the knee brace bolts to the inner face (Figure 14).

**Check before moving on.** A straight rod passes square through each pair of opposite holes.

### 3.4 Head cleats (make 8)

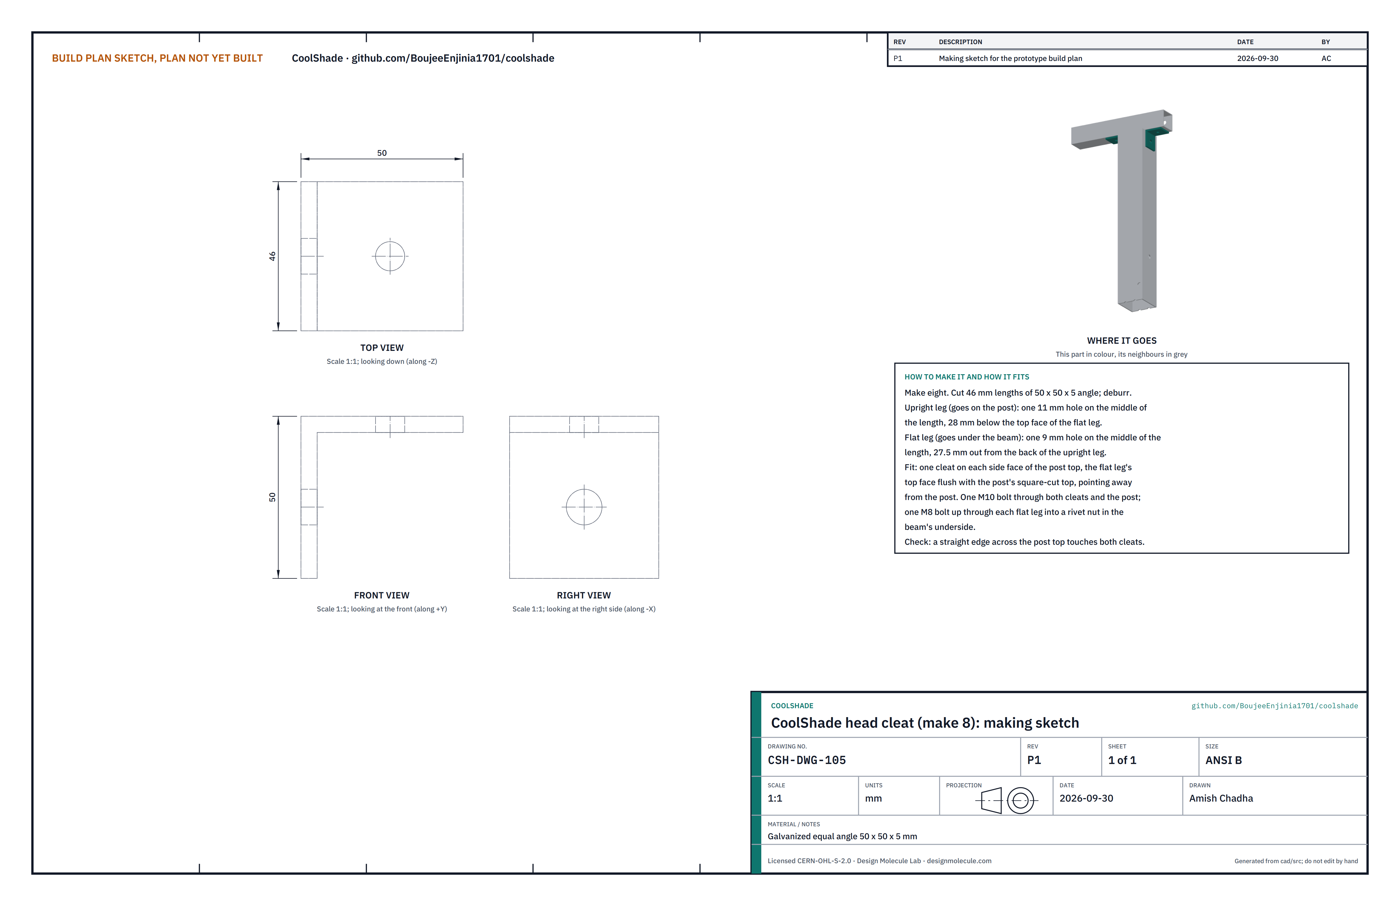
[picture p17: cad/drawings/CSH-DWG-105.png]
Figure 9. Making sketch of the head cleat


*Figure 9. Head cleat making sketch (CSH-DWG-105).*

**What it is and what it is made from.** A short angle each side of the post top that holds the long beam down. Galvanized equal angle 50 x 50 x 5 mm.

**How to make it.**

1. Cut eight 46 mm lengths; deburr.
2. Upright leg: one 11 mm hole at mid-length, 28 mm below the top face of the flat leg.
3. Flat leg: one 9 mm hole at mid-length, 27.5 mm out from the back of the upright leg.

**How it fits the parts next to it.**

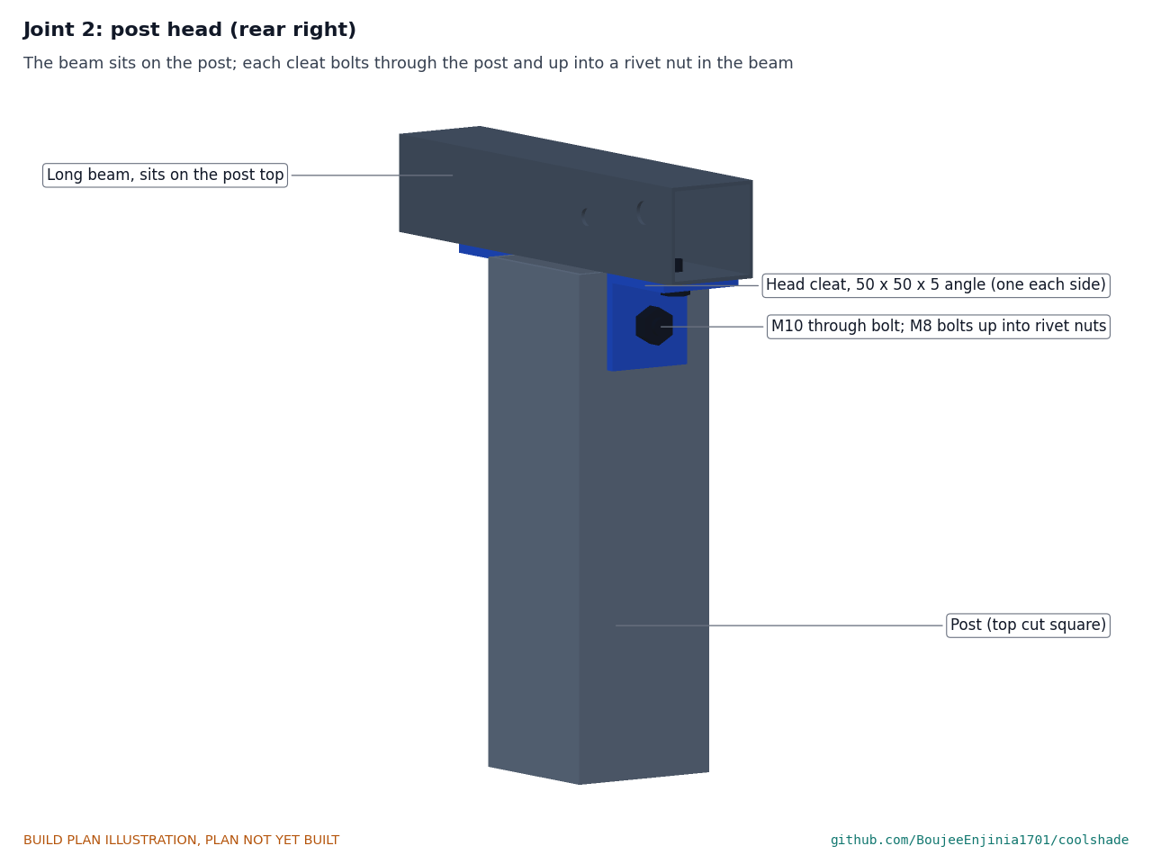
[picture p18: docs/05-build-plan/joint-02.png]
Figure 10. Joint 2: post head


*Figure 10. The long beam sits on the square-cut post top; a cleat each side, flat legs flush with the post top, pointing away from the post.*

One M10 bolt passes through both cleats and the post; one M8 bolt goes up through each flat leg into a rivet nut in the beam's underside.

**Check before moving on.** A straight edge across the post top touches both cleats' flat legs.

### 3.5 Long beams (make 2)

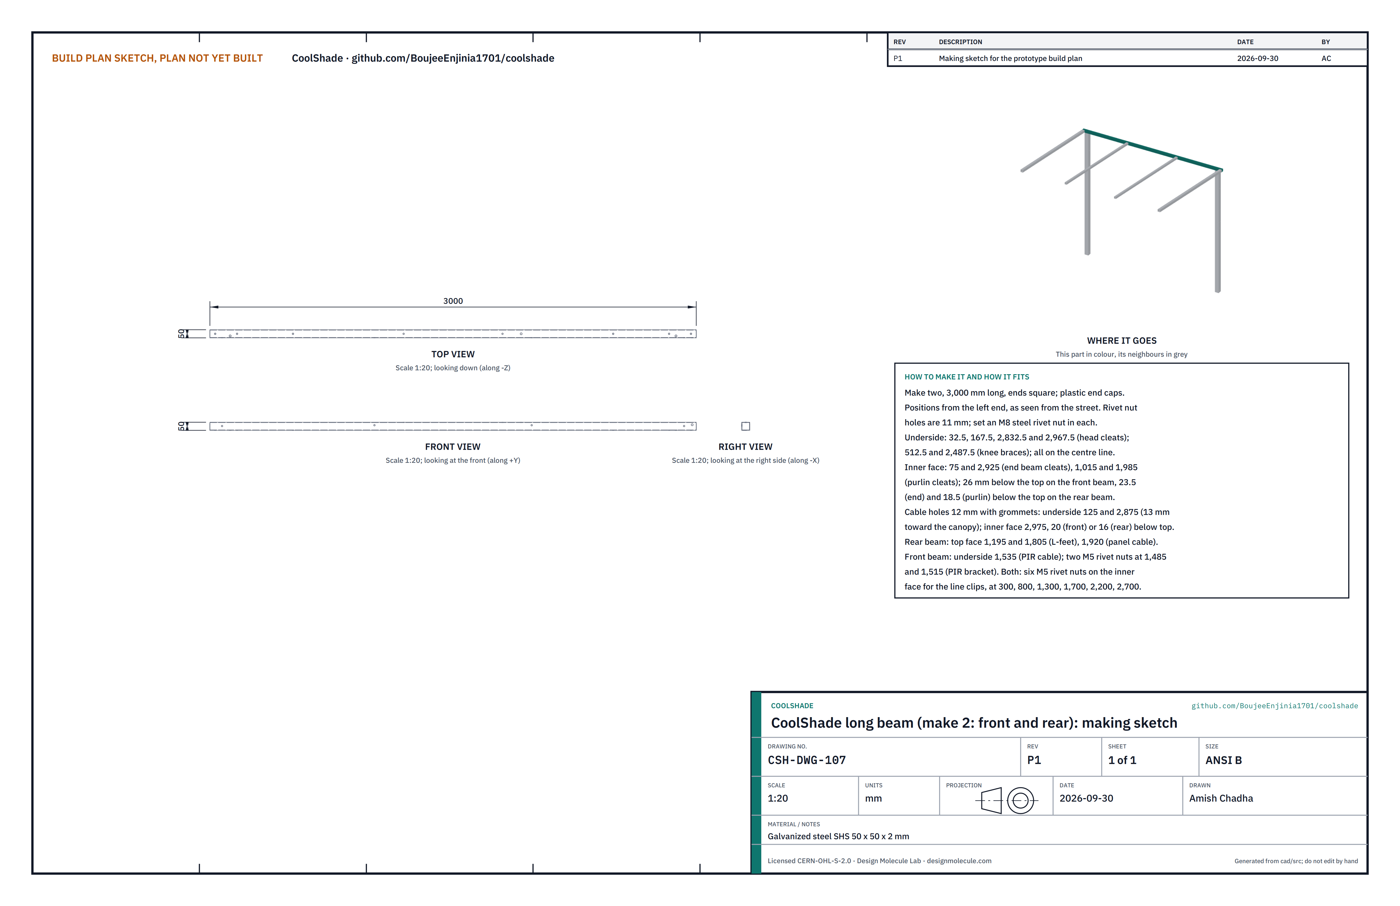
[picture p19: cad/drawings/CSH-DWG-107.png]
Figure 11. Making sketch of the long beam


*Figure 11. Long beam making sketch (CSH-DWG-107).*

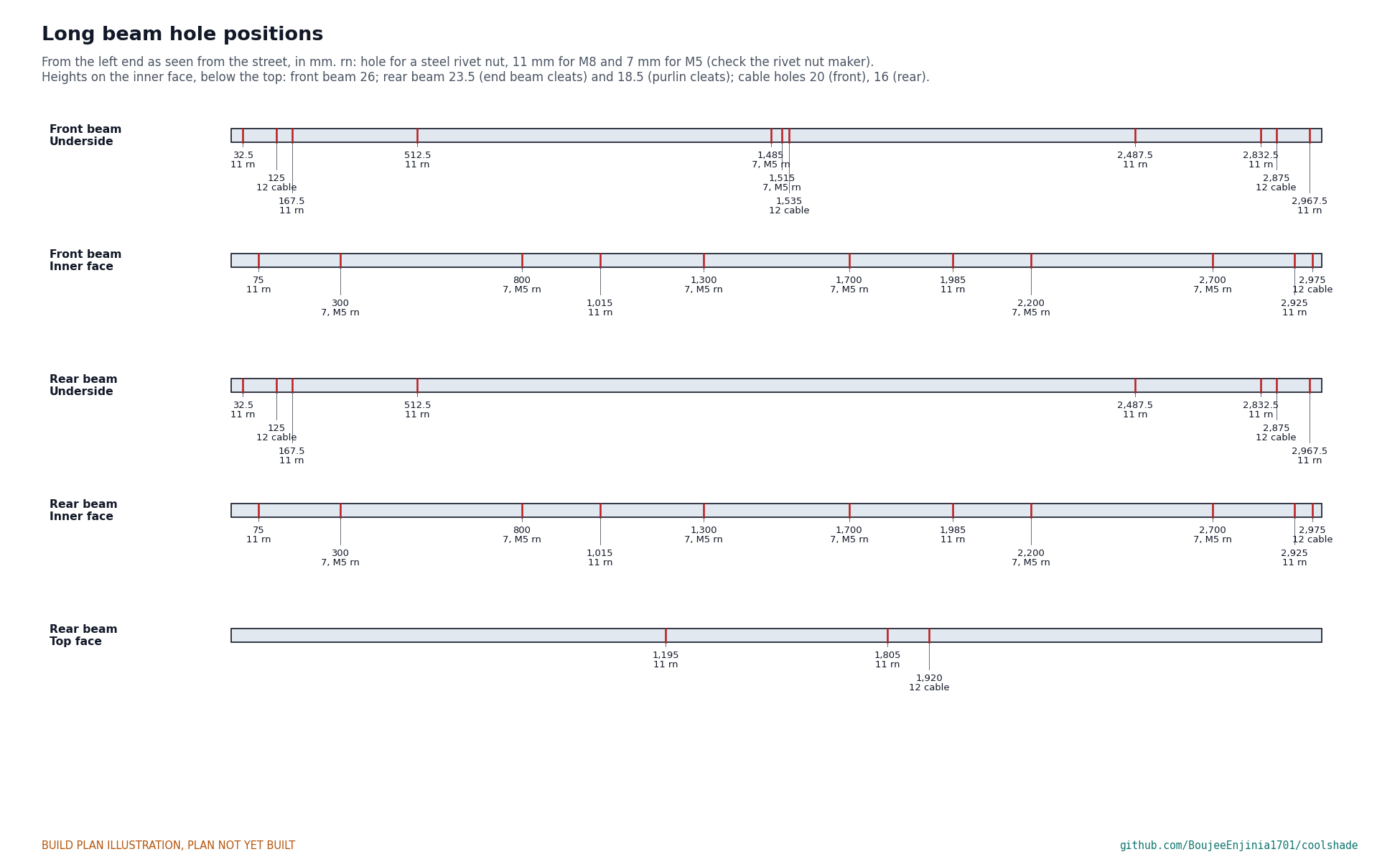
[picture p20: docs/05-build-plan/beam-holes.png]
Figure 12. Long beam hole positions


*Figure 12. Every hole in the two long beams, from the left end.*

**What it is and what it is made from.** The two horizontal beams along the street and rear edges of the roof. Galvanized steel SHS 50 x 50 x 2 mm, 3,000 mm long.

**How to make it.**

1. Cut two beams 3,000 mm long, ends square. Mark the left end and which beam is the front.
2. Drill every hole in Figure 12, measured from the left end: in the underside for the head cleats and knee braces, in the inner face for the frame cleats and the line clips, in the rear beam's top face for the L-feet, and the 12 mm cable holes.
3. Set an M8 steel rivet nut in each 11 mm hole and an M5 rivet nut in each 7 mm hole with the hand rivet nut tool. Fit grommets in the cable holes and plastic caps in the ends.

**How it fits the parts next to it.** Each beam sits centred on two post tops, overhanging each post's centre by 100 mm (Figure 10). The end beams, purlins and cleats meet its inner face (Figures 17 and 18); the cloth laces round it.

**Check before moving on.** Lay the beam on two trestles with the head cleats bolted on in their places: the cleat bolts start by hand in every rivet nut.

### 3.6 Knee braces (make 4)

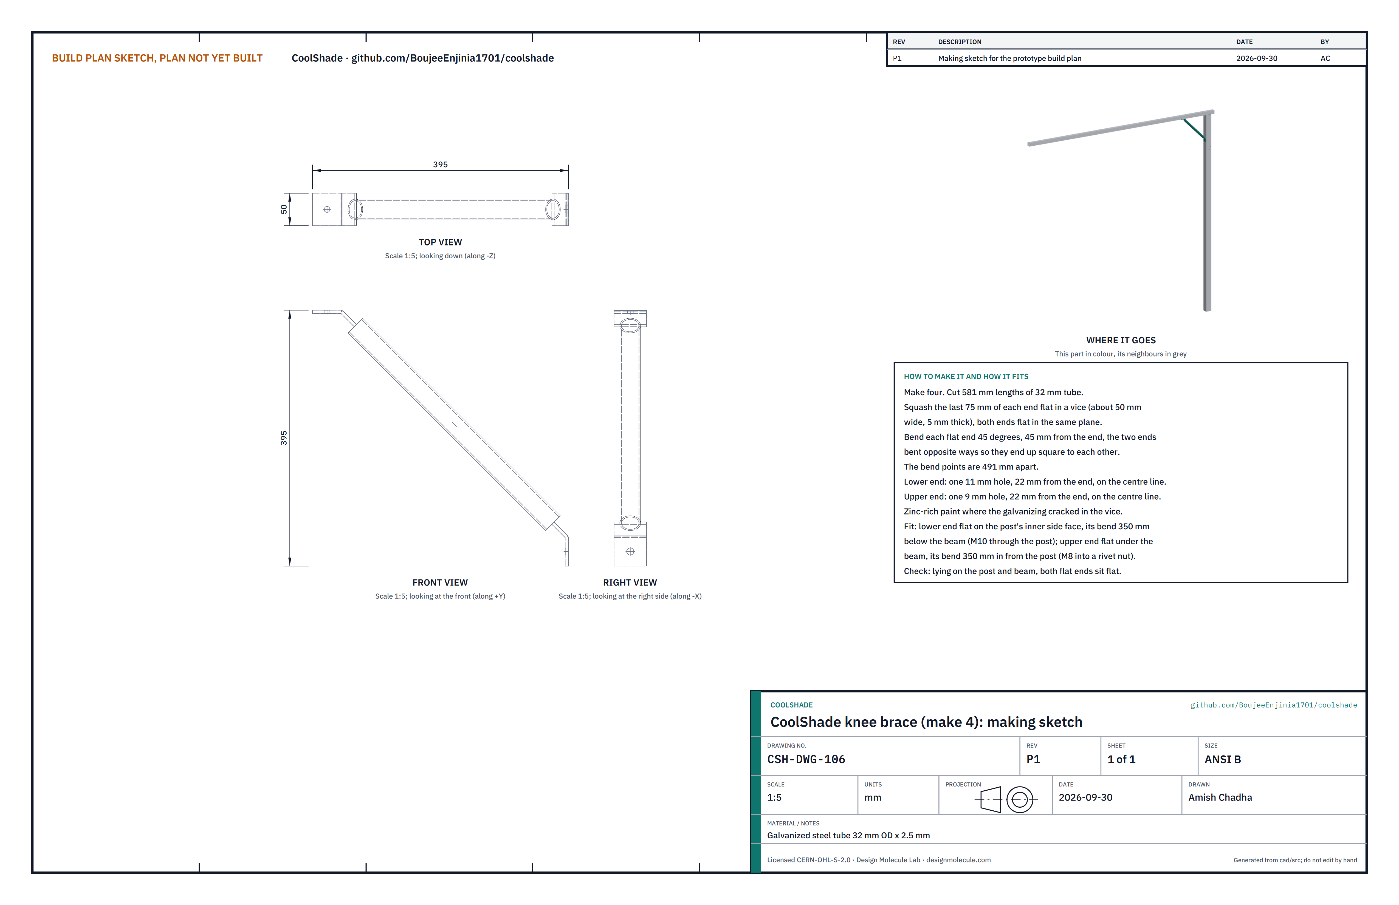
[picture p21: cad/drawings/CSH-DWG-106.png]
Figure 13. Making sketch of the knee brace


*Figure 13. Knee brace making sketch (CSH-DWG-106).*

**What it is and what it is made from.** A short diagonal from each post to its long beam that stiffens the corner. Galvanized steel tube 32 mm outside diameter, 2.5 mm wall.

**How to make it.**

1. Cut four 581 mm lengths.
2. Squash the last 75 mm of each end flat in a vice, to about 50 mm wide and 5 mm thick, both ends flat in the same plane.
3. Bend each flat end 45°, 45 mm from the end, the two ends bent opposite ways so they end square to each other; the bends are 491 mm apart.
4. Drill an 11 mm hole 22 mm from the lower end and a 9 mm hole 22 mm from the upper end, on the centre line.
5. Paint the flattened ends where the zinc has cracked.

**How it fits the parts next to it.**

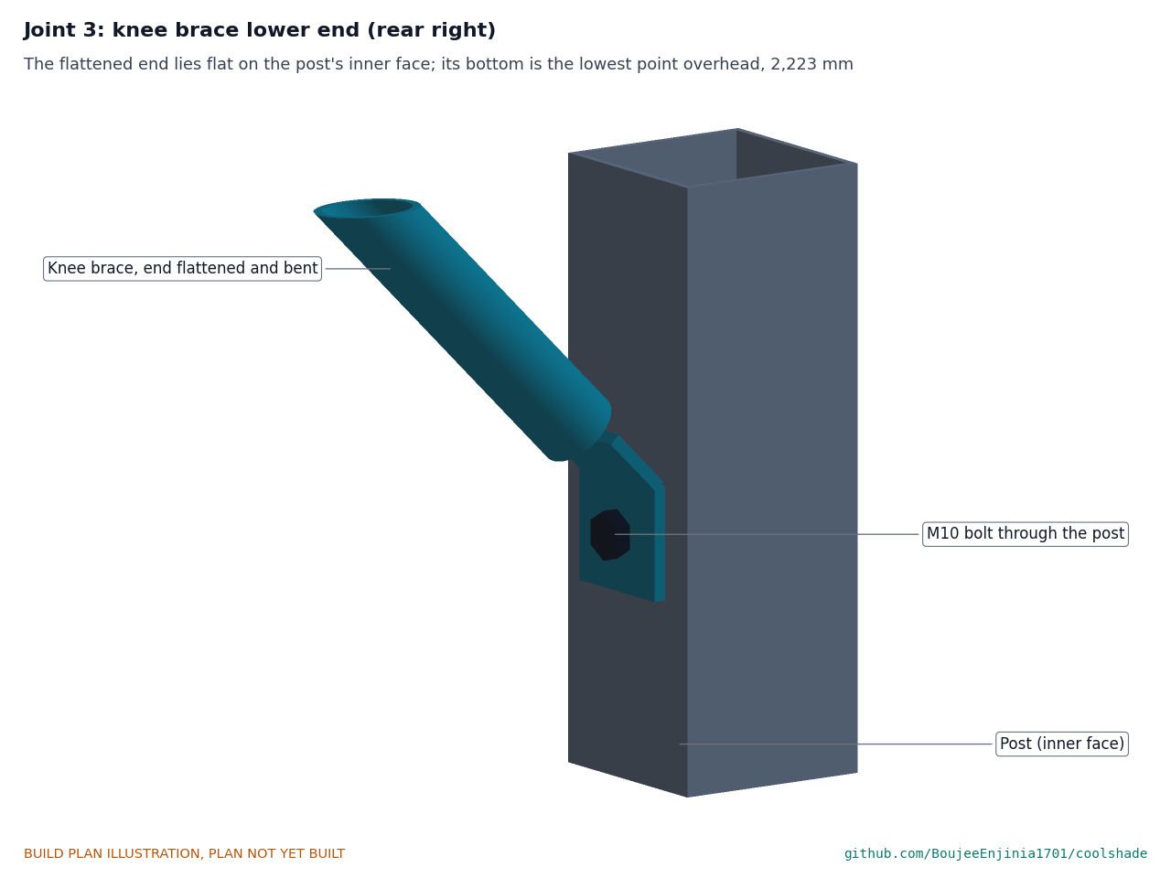
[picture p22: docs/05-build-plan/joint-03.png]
Figure 14. Joint 3: knee brace lower end


*Figure 14. The lower end lies flat on the post's inner face, its bend 350 mm below the beam; one M10 bolt through the post.*

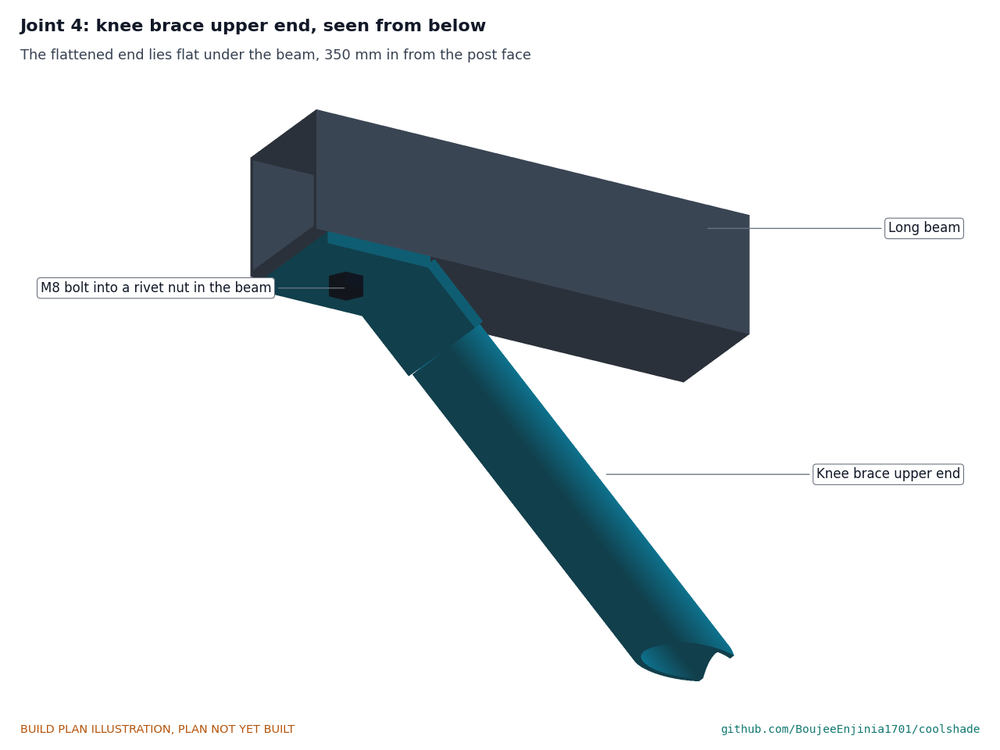
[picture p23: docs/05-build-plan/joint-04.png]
Figure 15. Joint 4: knee brace upper end


*Figure 15. The upper end lies flat under the beam, its bend 350 mm in from the post; one M8 bolt into a rivet nut.*

The bottom of the lower flat end is the lowest point overhead in the canopy: 2,223 mm above the slab at the rear posts.

**Check before moving on.** Held to a post and beam offcut set square, both flat ends sit flat without forcing.

### 3.7 Frame cleats (make 10)

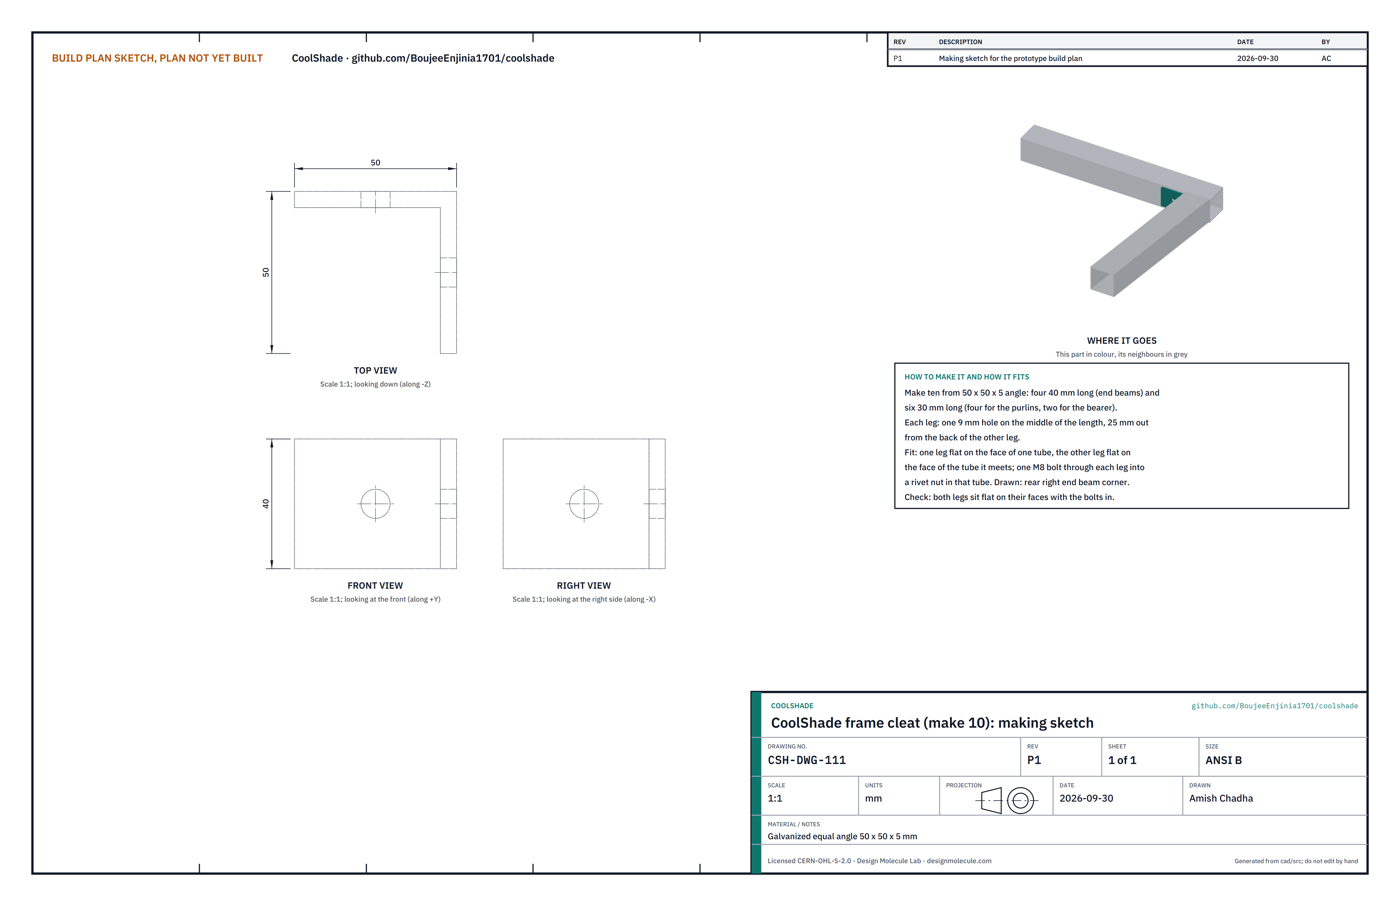
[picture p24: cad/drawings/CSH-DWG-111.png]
Figure 16. Making sketch of the frame cleat


*Figure 16. Frame cleat making sketch (CSH-DWG-111).*

**What it is and what it is made from.** The angle that joins a tube to the face of the tube it butts against. Galvanized equal angle 50 x 50 x 5 mm: four 40 mm long (end beams) and six 30 mm long (four for the purlins, two for the bearer).

**How to make it.**

1. Cut the ten lengths; deburr.
2. Drill one 9 mm hole in each leg at mid-length, 25 mm out from the back of the other leg.

**How it fits the parts next to it.**

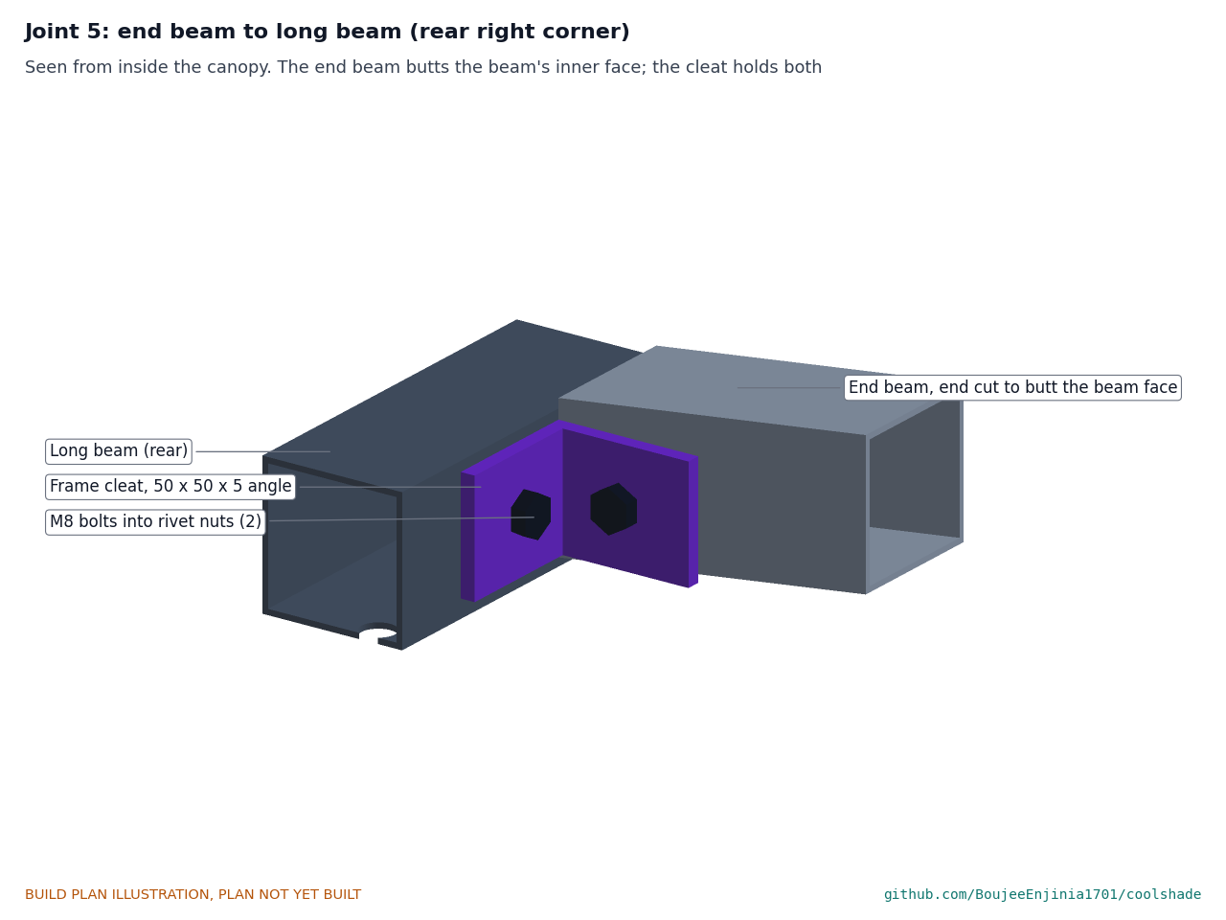
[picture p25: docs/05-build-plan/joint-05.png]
Figure 17. Joint 5: end beam to long beam


*Figure 17. The end beam's end butts flat against the long beam's inner face; the cleat sits in the inside corner with one M8 bolt into a rivet nut in each tube.*

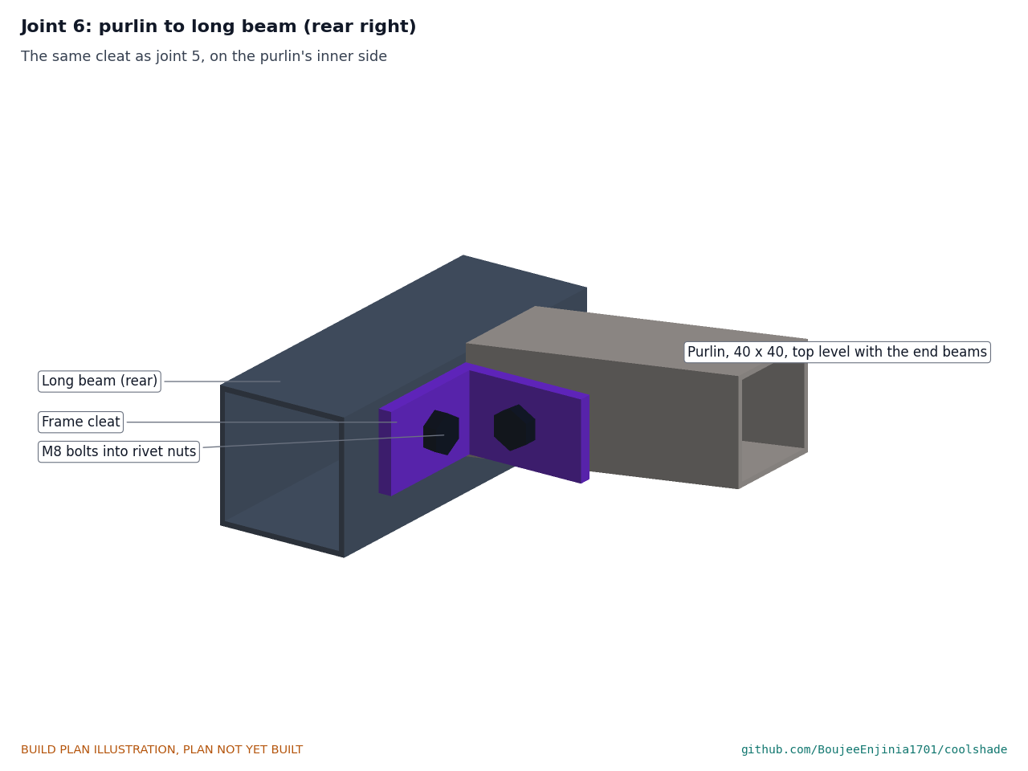
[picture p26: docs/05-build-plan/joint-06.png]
Figure 18. Joint 6: purlin to long beam


*Figure 18. The purlin joins the long beam the same way, with a 30 mm cleat on its inner side.*

**Check before moving on.** Both legs sit flat on their faces with the bolts in.

### 3.8 End beams (make 2)

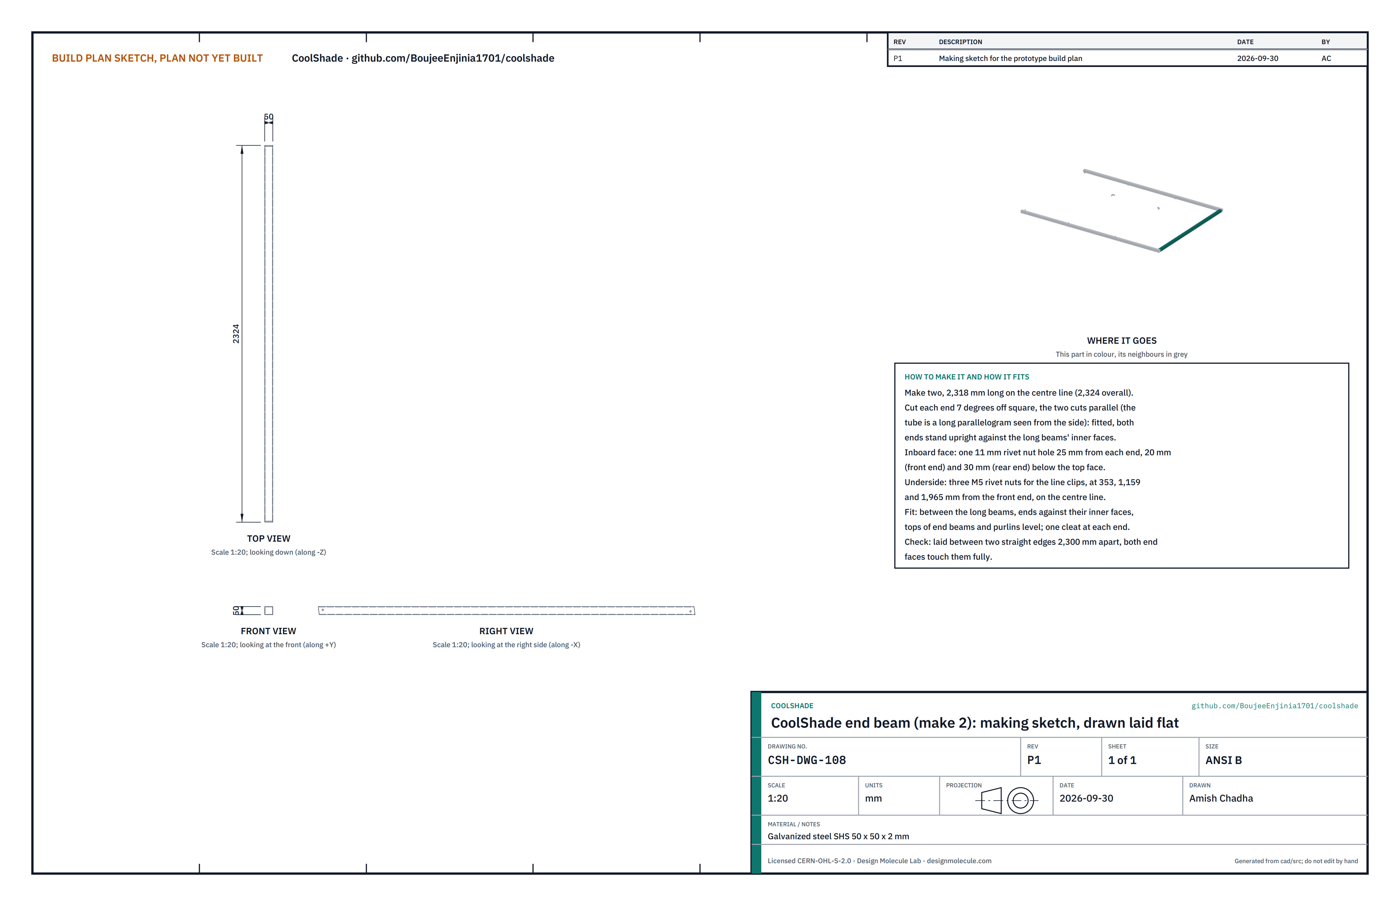
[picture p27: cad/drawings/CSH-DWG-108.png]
Figure 19. Making sketch of the end beam


*Figure 19. End beam making sketch (CSH-DWG-108), drawn laid flat.*

**What it is and what it is made from.** The two sloping beams at the left and right ends of the roof. Galvanized steel SHS 50 x 50 x 2 mm.

**How to make it.**

1. Cut two lengths 2,318 mm on the centre line, each end cut 7° off square with the two cuts parallel, so that fitted on the slope both ends stand upright.
2. Inboard face: one 11 mm rivet nut hole 25 mm from each end, 20 mm below the top face at the front end and 30 mm at the rear end. Underside: three 7 mm holes 353, 1,159 and 1,965 mm from the front end, on the centre line (line clips).
3. Set the rivet nuts.

**How it fits the parts next to it.** The end beams go between the long beams at the very ends of the roof, their outer faces level with the long beams' ends, ends flat against the long beams' inner faces (Figure 17). The mist line hangs under them (Figure 34).

**Check before moving on.** Laid between two straight edges 2,300 mm apart, both end faces touch them fully.

### 3.9 Purlins (make 2)

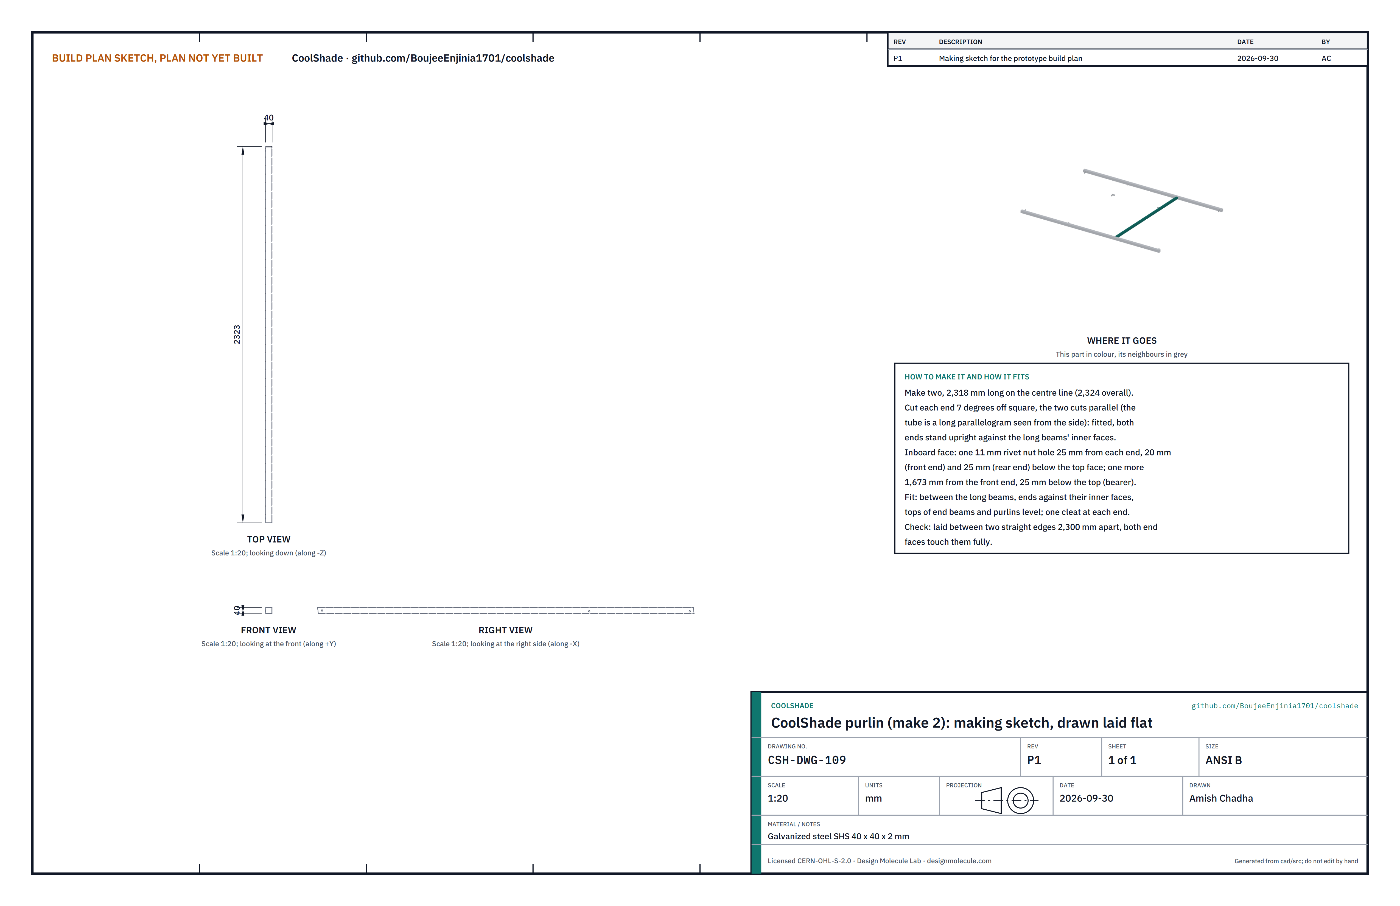
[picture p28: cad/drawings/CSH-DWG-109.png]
Figure 20. Making sketch of the purlin


*Figure 20. Purlin making sketch (CSH-DWG-109), drawn laid flat.*

**What it is and what it is made from.** Two lighter sloping tubes that carry the middle of the cloth and the panel bearer. Galvanized steel SHS 40 x 40 x 2 mm.

**How to make it.**

1. Cut two lengths 2,318 mm on the centre line, ends cut as for the end beams.
2. Inboard face: one 11 mm rivet nut hole 25 mm from each end (20 mm below the top at the front end, 25 mm at the rear end) and one 1,673 mm from the front end, 25 mm below the top (bearer cleat). Set the rivet nuts.

**How it fits the parts next to it.** The purlins stand 530 mm each side of the roof's centre line, tops level with the end beams (Figure 18). Their inner faces frame the notch in the cloth.

**Check before moving on.** As for the end beams.

### 3.10 Panel bearer (make 1)

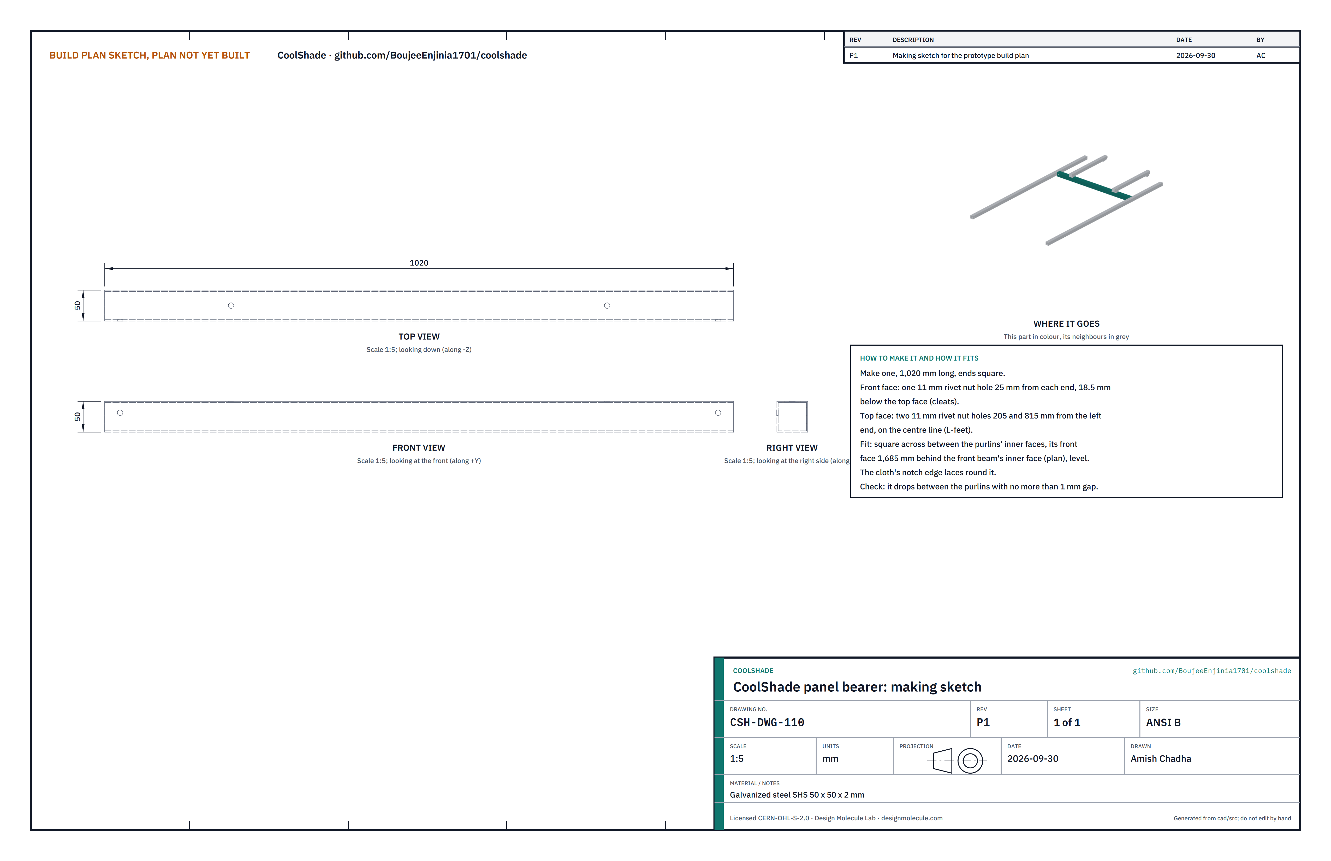
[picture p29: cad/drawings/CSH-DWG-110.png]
Figure 21. Making sketch of the panel bearer


*Figure 21. Panel bearer making sketch (CSH-DWG-110).*

**What it is and what it is made from.** A short cross tube between the purlins that carries the front feet of the panel rails. Galvanized steel SHS 50 x 50 x 2 mm, 1,020 mm long.

**How to make it.**

1. Cut 1,020 mm, ends square.
2. Front face: one 11 mm rivet nut hole 25 mm from each end, 18.5 mm below the top. Top face: two 11 mm rivet nut holes 205 and 815 mm from the left end, on the centre line. Set the rivet nuts.

**How it fits the parts next to it.**

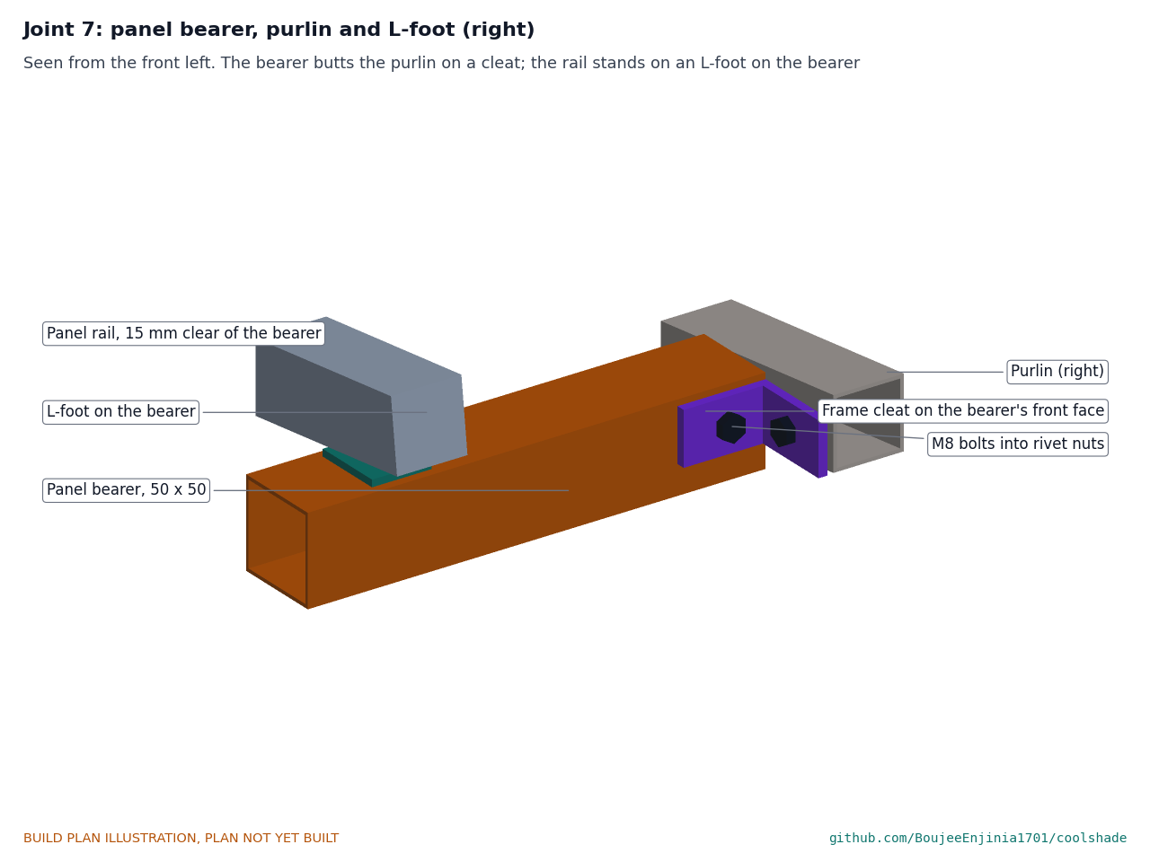
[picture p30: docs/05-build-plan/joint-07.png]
Figure 22. Joint 7: panel bearer, purlin and L-foot


*Figure 22. The bearer butts square against the purlins' inner faces on two 30 mm cleats; the rail's L-foot stands on its top.*

Its front face is 1,685 mm behind the front beam's inner face, measured level; the front edge of the cloth's notch laces round it.

**Check before moving on.** It drops between the purlins with no more than 1 mm to spare and sits level.

### 3.11 Enclosure rails (make 2)

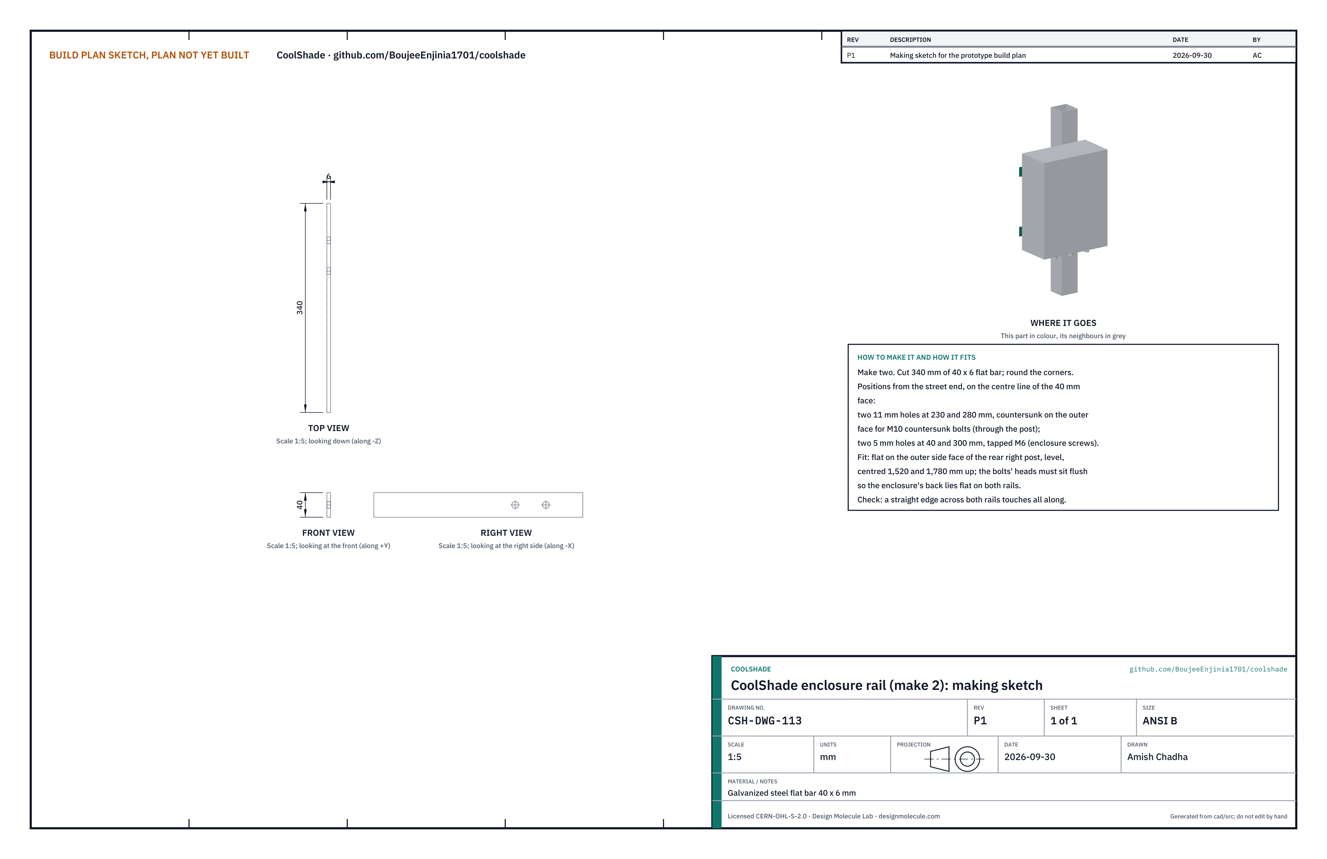
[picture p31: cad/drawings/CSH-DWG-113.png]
Figure 23. Making sketch of the enclosure rail


*Figure 23. Enclosure rail making sketch (CSH-DWG-113).*

**What it is and what it is made from.** Two flat bars on the rear right post that the enclosure screws to. Galvanized steel flat bar 40 x 6 mm, 340 mm long.

**How to make it.**

1. Cut two lengths; round the corners.
2. On the centre line, from the street end: two 11 mm holes at 230 and 280 mm, countersunk on the outer face for M10 countersunk bolts; two 5 mm holes at 40 and 300 mm, tapped M6.

**How it fits the parts next to it.** The rails lie level on the rear right post's outer face, centred 1,520 and 1,780 mm above the slab, with the bolt heads flush; the enclosure's back lies flat on both (Figure 31).

**Check before moving on.** A straight edge across both rails touches all along.

### 3.12 Sensor arm (make 1)

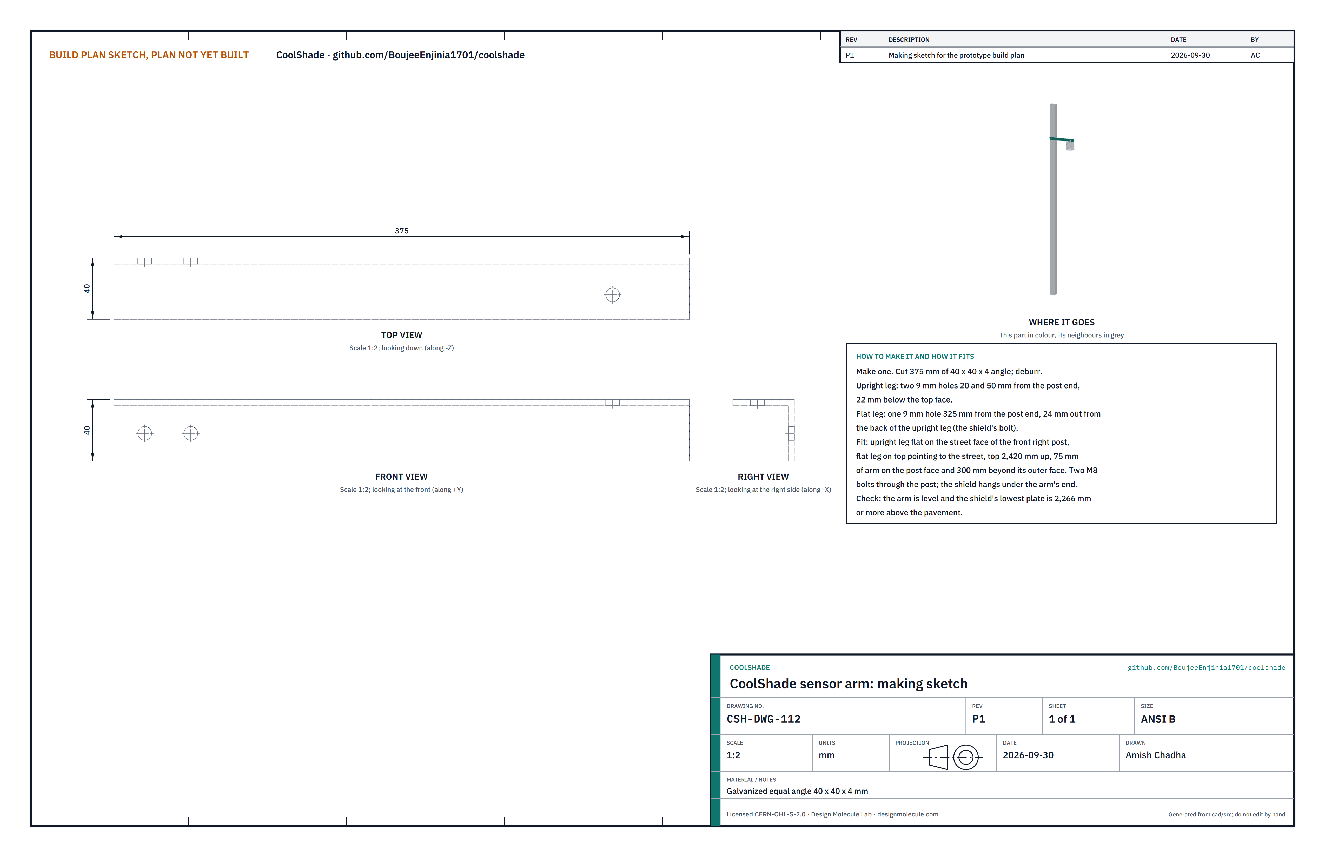
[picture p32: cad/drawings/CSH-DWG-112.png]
Figure 24. Making sketch of the sensor arm


*Figure 24. Sensor arm making sketch (CSH-DWG-112).*

**What it is and what it is made from.** The bracket that holds the temperature and humidity sensor outside the mist zone. Galvanized equal angle 40 x 40 x 4 mm, 375 mm long.

**How to make it.**

1. Cut 375 mm; deburr.
2. Upright leg: two 9 mm holes 20 and 50 mm from the post end, 22 mm below the top.
3. Flat leg: one 9 mm hole 325 mm from the post end, 24 mm out from the back of the upright leg.

**How it fits the parts next to it.** The upright leg lies flat on the street face of the front right post, top 2,420 mm up, 75 mm on the post and 300 mm beyond it; two M8 bolts through the post. The shield hangs under the arm's end on one M8 bolt (Figure 32).

**Check before moving on.** The arm is level and the shield's lowest plate is at least 2,266 mm above the slab.

### 3.13 Equipment plate (make 1)

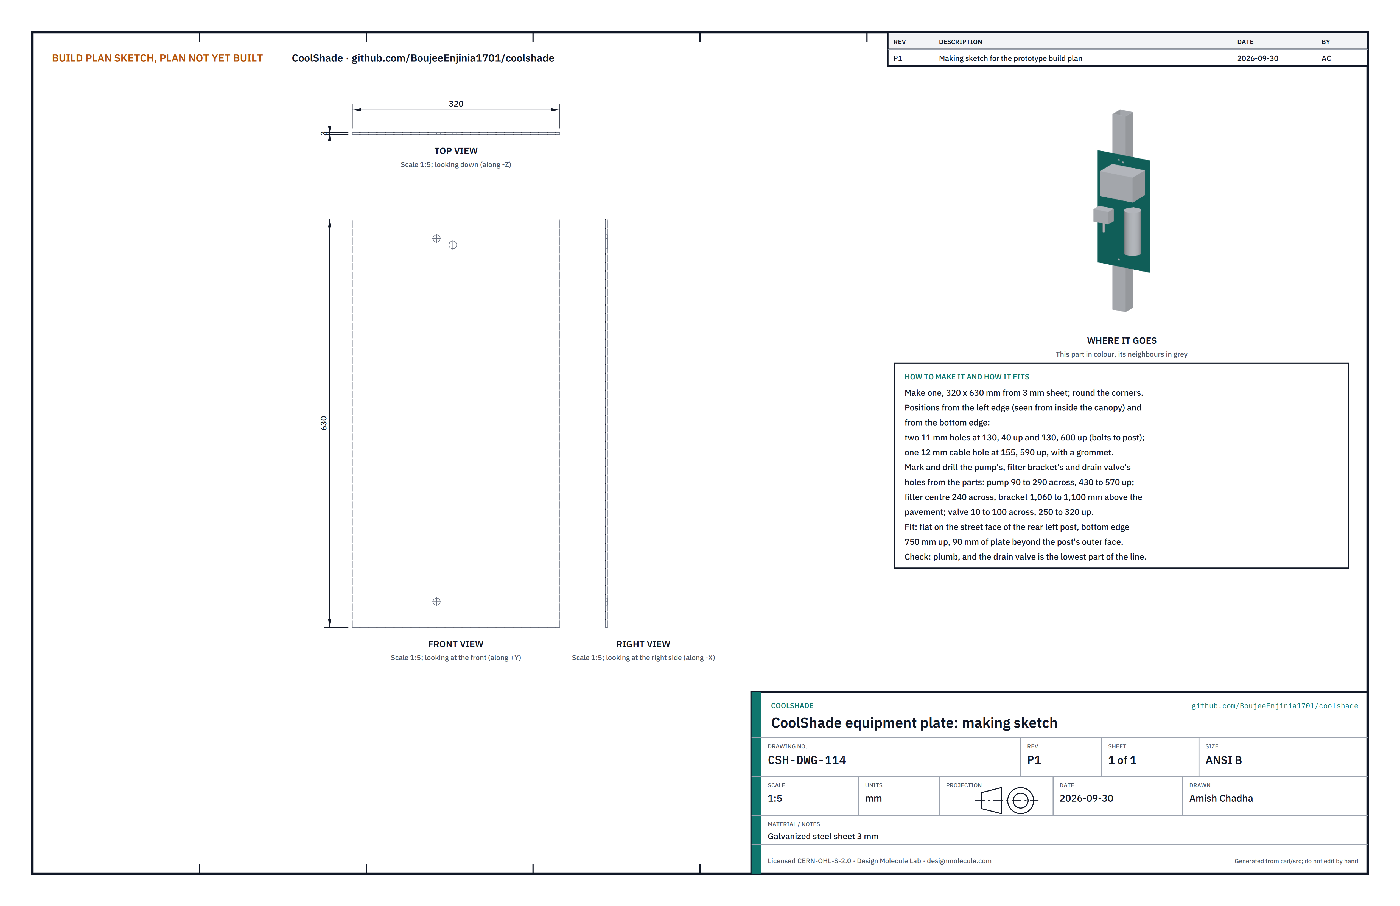
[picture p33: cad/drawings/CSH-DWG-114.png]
Figure 25. Making sketch of the equipment plate


*Figure 25. Equipment plate making sketch (CSH-DWG-114).*

**What it is and what it is made from.** The plate on the rear left post that carries the pump, filter and drain valve. Galvanized steel sheet 3 mm, 320 x 630 mm.

**How to make it.**

1. Cut the sheet; round the corners.
2. Measured from the left edge (seen from inside the canopy) and from the bottom edge: two 11 mm holes at 130 across, 40 and 600 up; one 12 mm cable hole at 155 across, 590 up, with a grommet.
3. Lay the pump (90 to 290 across, 430 to 570 up), the filter bracket (centre 240 across, bracket 310 to 350 up) and the drain valve (10 to 100 across, 250 to 320 up) on the plate, mark their holes through their feet and drill to suit.

**How it fits the parts next to it.** The plate lies flat on the street face of the rear left post, bottom edge 750 mm up, with 90 mm beyond the post's outer face; two M10 bolts through the post (Figure 33).

**Check before moving on.** With the parts laid on it, the drain valve is the lowest of the three and sits directly under where the down pipe comes down.

### 3.14 Tank stop cleats (make 2)

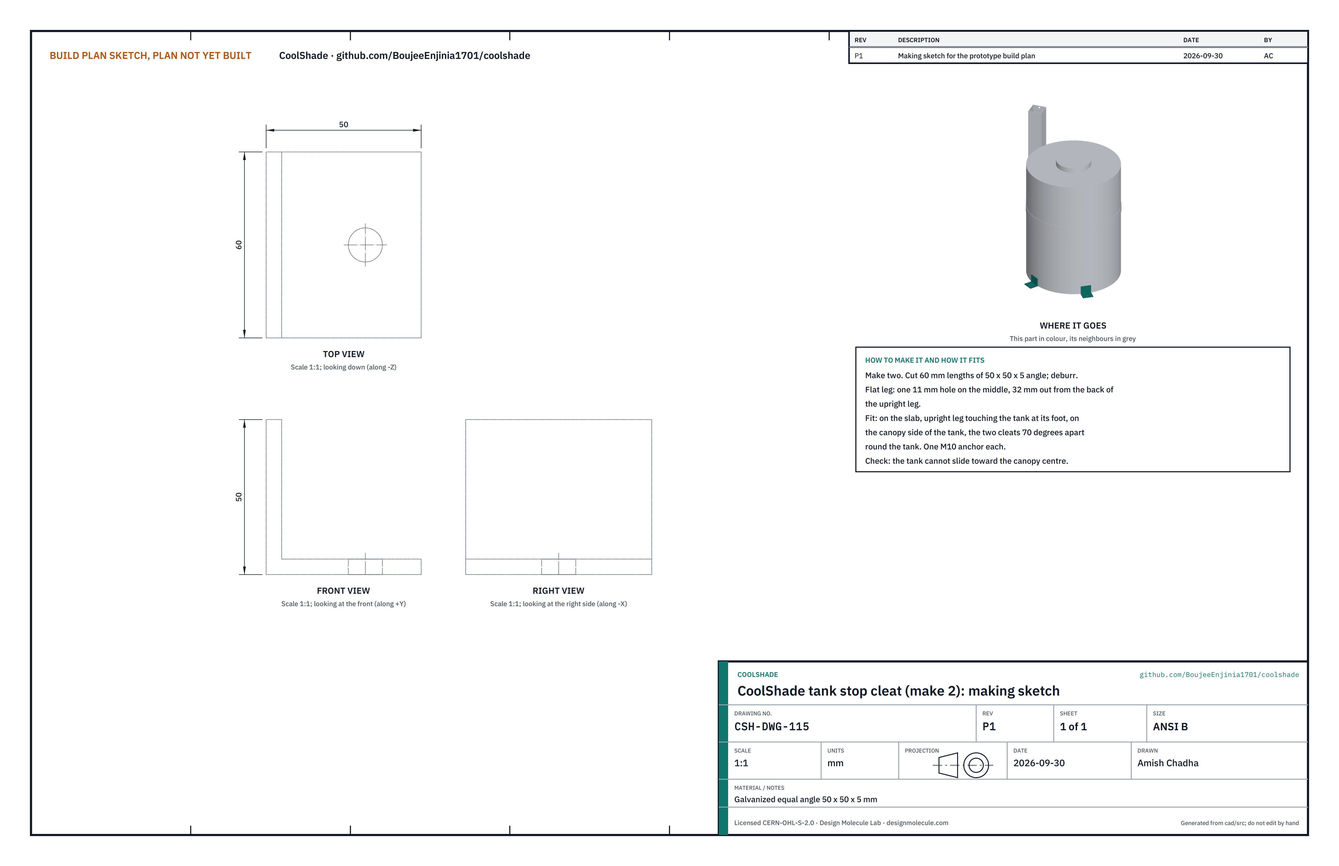
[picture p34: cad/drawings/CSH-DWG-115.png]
Figure 26. Making sketch of the tank stop cleat


*Figure 26. Tank stop cleat making sketch (CSH-DWG-115).*

**What it is and what it is made from.** Two short angles anchored to the slab against the tank's foot. Galvanized equal angle 50 x 50 x 5 mm, 60 mm long.

**How to make it.** Cut two 60 mm lengths; drill one 11 mm hole in the flat leg at mid-length, 32 mm out from the back of the upright leg.

**How it fits the parts next to it.** On the canopy side of the tank, 70° apart round it, upright legs touching the tank's foot, one M10 anchor each (Figure 35).

**Check before moving on.** The tank cannot slide toward the canopy's centre.

### 3.15 Shade fabric (bought, made to size)

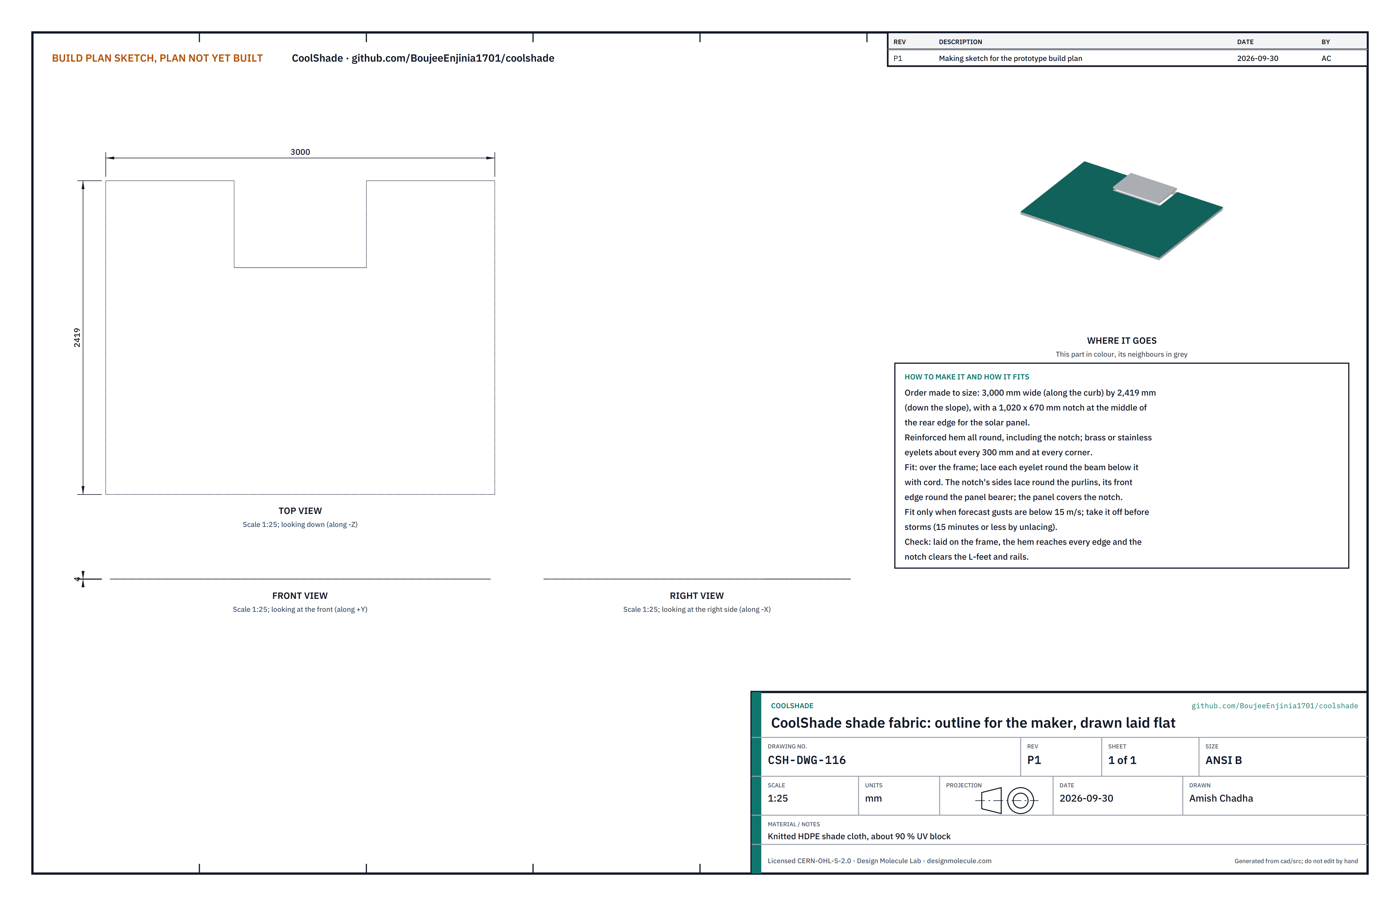
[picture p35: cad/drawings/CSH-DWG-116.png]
Figure 27. Outline of the shade fabric


*Figure 27. Shade fabric outline for the maker (CSH-DWG-116), drawn laid flat.*

**What it is and what it is made from.** Knitted HDPE shade cloth, about 90 % UV block, made to order: 3,000 mm along the curb by 2,419 mm down the slope, with a 1,020 x 670 mm notch at the middle of the rear edge for the panel. Reinforced hem all round, including the notch, with brass or stainless eyelets about every 300 mm and at every corner, and lacing cord.

**How it fits the parts next to it.** It lies over the frame; each eyelet is laced round the tube below it. The notch's sides lace round the purlins and its front edge round the panel bearer, between the L-feet; the panel covers the notch. It is fitted last (step 17), only when forecast gusts are below 15 m/s, and taken off before storms by unlacing, in 15 minutes or less (R10).

**Check before moving on.** On delivery, lay it out and measure it against Figure 27.

### 3.16 Wiring and water circuit

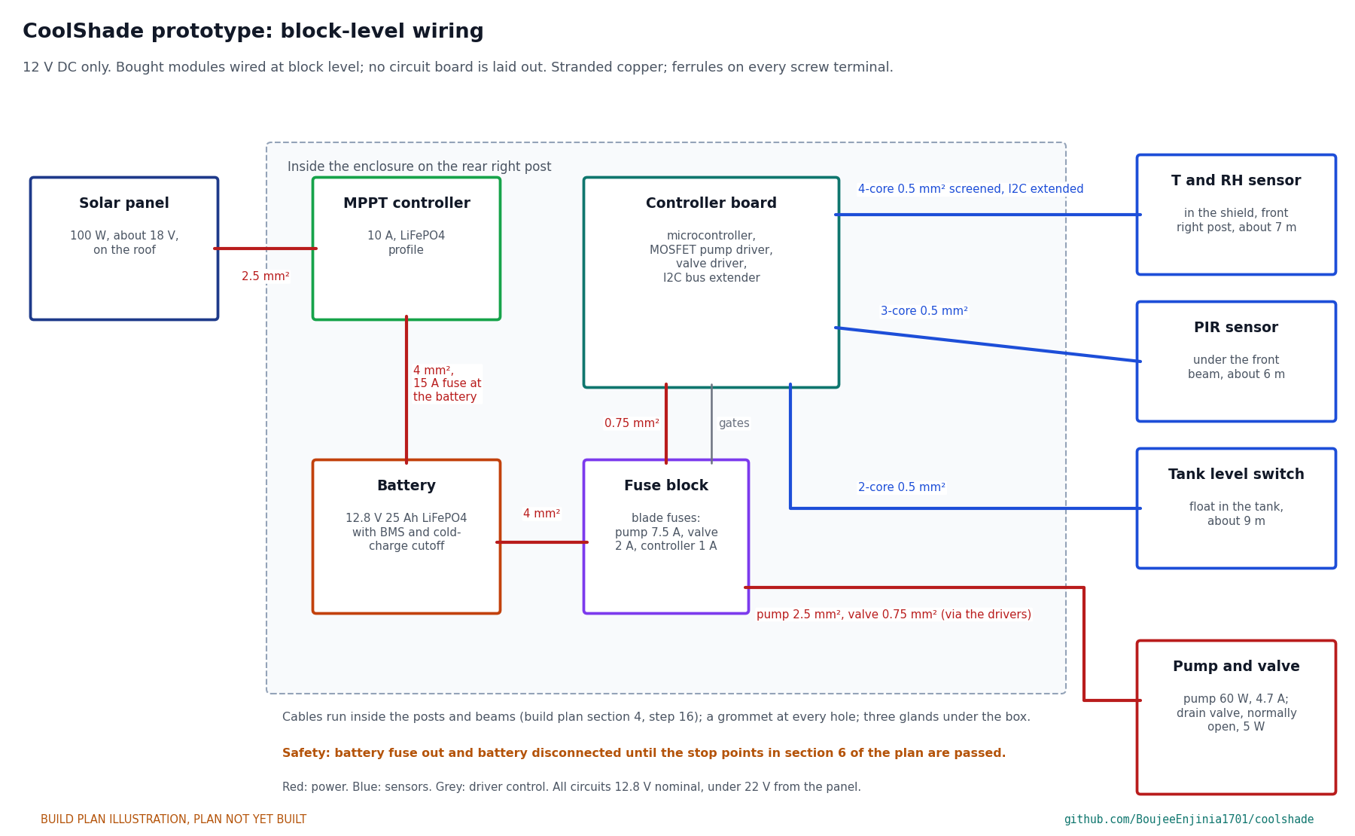
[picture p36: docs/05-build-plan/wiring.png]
Figure 28. Block-level wiring


*Figure 28. Block-level wiring with wire sizes. No circuit board is laid out at this stage; bought modules are wired together.*

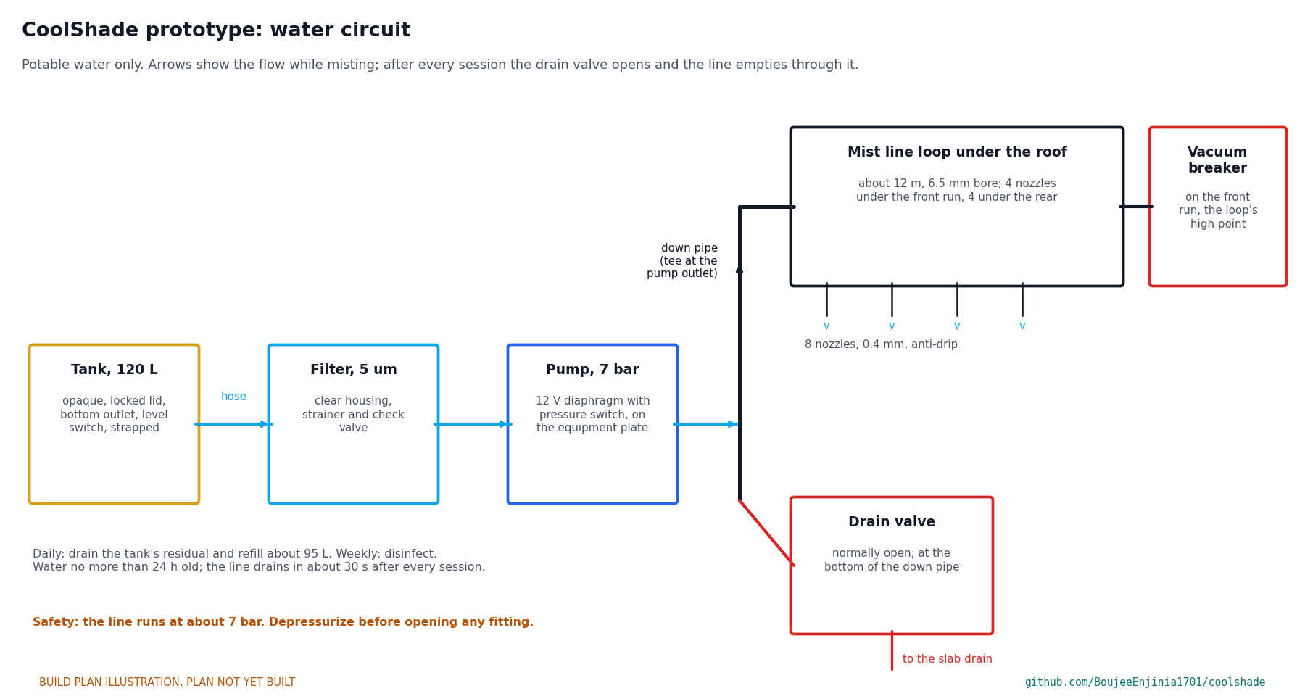
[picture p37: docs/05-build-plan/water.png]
Figure 29. Water circuit


*Figure 29. Water circuit from the tank to the nozzles and the drain.*

Wire it like this, with stranded copper and a ferrule on every screw terminal:

1. Solar panel to the charge controller's panel input: 2.5 mm², inside the rear beam and the rear right post.
2. Charge controller to the battery, through the 15 A fuse at the battery terminal: 4 mm².
3. Battery to the fuse block: 4 mm². Fuse block to the controller board: 0.75 mm², 1 A fuse.
4. Pump driver to the pump: 2.5 mm², 7.5 A fuse; valve driver to the drain valve: 0.75 mm², 2 A fuse. Both cables run inside the rear beam and the rear left post and come out through the equipment plate.
5. Temperature and humidity sensor: 4-core 0.5 mm² screened cable, about 7 m, with the I2C bus extender board at each end.
6. PIR sensor: 3-core 0.5 mm², about 6 m. Tank level switch: 2-core 0.5 mm², about 9 m.

Water: tank outlet to the filter inlet, filter outlet to the pump inlet, both with clamped potable-grade hose; the pump outlet joins the down pipe through a tee, the loop runs from the top of the down pipe, and the normally open drain valve sits at its bottom. The vacuum breaker sits on a tee in the front run, the loop's highest part.

**Check before moving on.** Every wire continues end to end and is labelled; with the battery disconnected, nothing reads short to the enclosure.

### 3.17 Bought components

Buy to specification, not brand. Line numbers are those of the bill of materials.

- **Solar panel and mounting kit (line 5).** 100 W monocrystalline, about 1,000 x 670 x 35 mm, Vmp about 18 V; two aluminium rails about 770 mm, four L-feet and four end clamps for a 35 mm frame. The L-feet stand on the bearer and the rear beam on M8 bolts into rivet nuts; the rails bolt to the feet 15 mm clear of the tubes (Figure 30).
- **Battery (line 6).** 12.8 V 25 Ah LiFePO4 with built-in battery management and cold-charge cutoff; fused at the terminal.
- **Charge controller (line 7).** 12 V, 10 A MPPT with a LiFePO4 profile.
- **Enclosure and controller (line 8).** Lockable IP65 box about 420 x 320 x 160 mm with moulded mounting holes outside the gasket and bosses for a gear plate; microcontroller board, MOSFET pump driver, valve driver, blade fuse block, three M20 cable glands drilled in its floor 134 mm out from the back.
- **Sensor head (line 9).** SHT4x-class temperature and humidity sensor in a multi-plate radiation shield with a top mounting plate; I2C bus extender pair; PIR presence sensor with a small bracket (two M5 rivet nuts under the front beam). No camera or microphone.
- **Pump (line 10).** 12 V diaphragm pump, about 7 bar, about 60 W, with pressure switch.
- **Filter (line 11).** 5 µm cartridge in a clear housing, inlet strainer and check valve.
- **Mist line (line 12).** About 12 m of 9.5 mm (3/8 in) misting line, 6.5 mm bore, slip-lok tees and elbows, eight 0.4 mm brass anti-drip nozzles, 18 hanger clips.
- **Tank (line 13).** 120 L opaque food-grade tank with lockable lid and bottom outlet, low-level float switch, ratchet strap.
- **Drain valve and vacuum breaker (line 14).** 12 V normally open solenoid valve with about a 3 mm orifice; air admittance valve.
- **Hose and cable (line 15).** Potable-grade hose and clamps, UV-stable outdoor cable, grommets.
- **Fixings (line 16).** Galvanized or stainless: 8 M12 x 110 and 8 M10 x 100 through bolts with nyloc nuts; 16 M16 anchors (line 4) and 2 M10 anchors; 36 M8 x 16 bolts into rivet nuts; 4 M10 countersunk bolts; 3 M8 bolts with nuts for the arm and shield; 2 M10 bolts for the equipment plate; M6 and M5 screws; washers; lacing cord.

## 4. Putting it together

In each picture the parts already fitted are grey and the parts being fitted are in colour, with an arrow showing the way they go in. Bolts are tightened only where a step says so; until then they are snug.

### Step 1: base plates and anchors on the slab

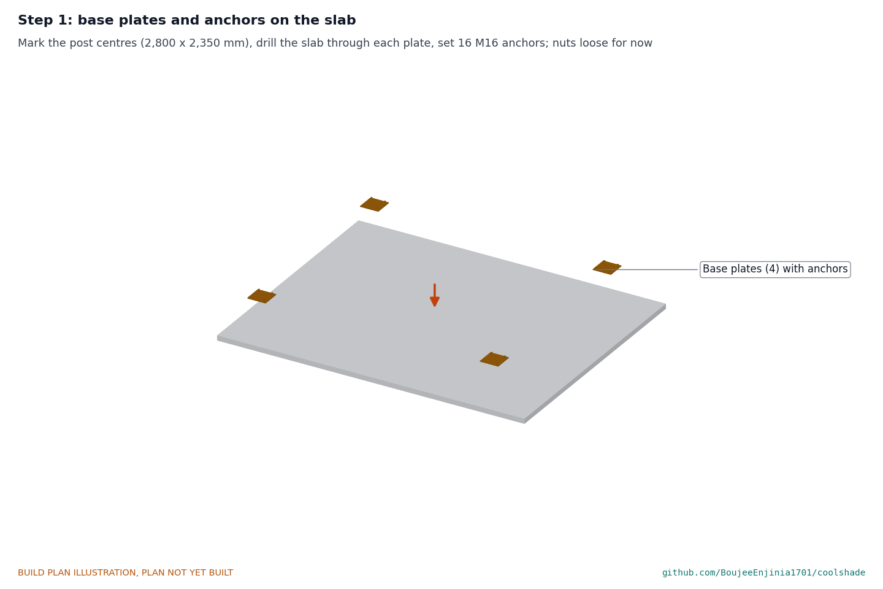
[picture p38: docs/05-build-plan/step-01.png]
Step 1


Set out the four post centres from Figure 2 and check both diagonals are 3,655 mm, give or take 5 mm. Using each base plate as a template, drill the slab for the M16 anchors to the anchor maker's depth and set them. **Hold point:** safety stop S1.

### Step 2: posts and base cleats

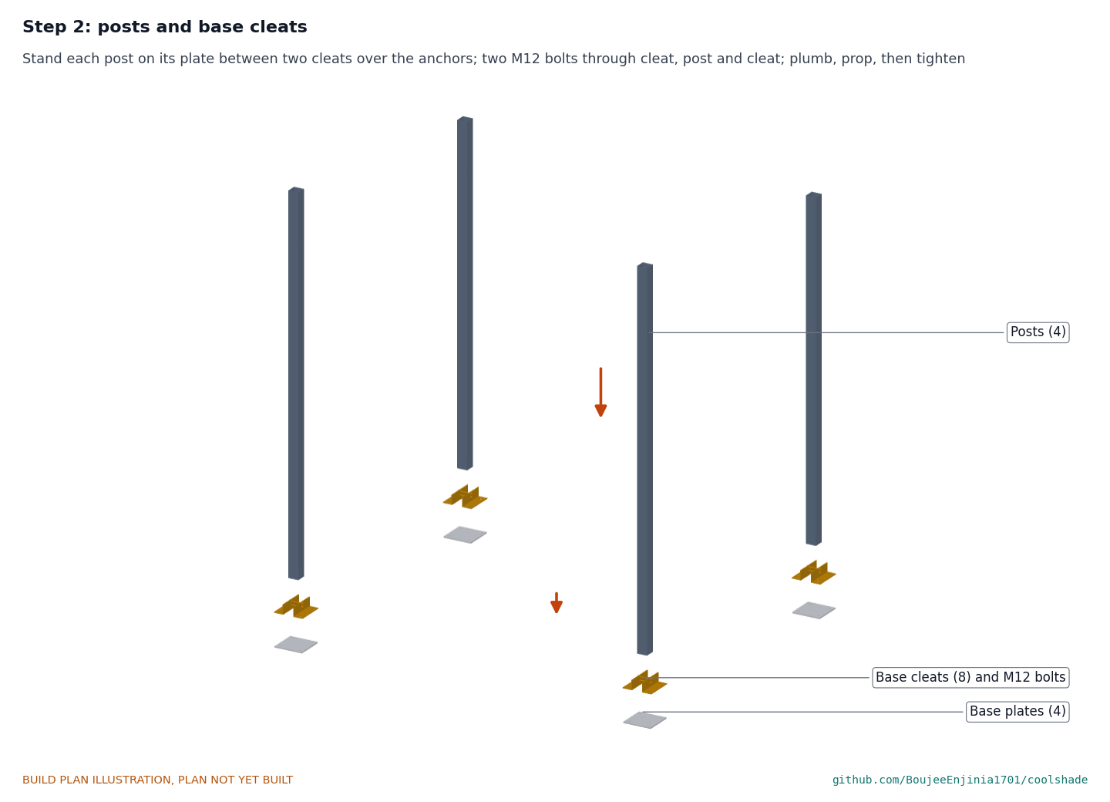
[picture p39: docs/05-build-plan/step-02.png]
Step 2


Two people stand each post on its plate; fit the two base cleats over the anchors and the two M12 bolts through cleat, post and cleat. Plumb the post both ways, prop it, then tighten the M12 bolts and the anchor nuts to the anchor maker's torque. **Hold point:** safety stop S2.

### Step 3: head cleats onto the post tops

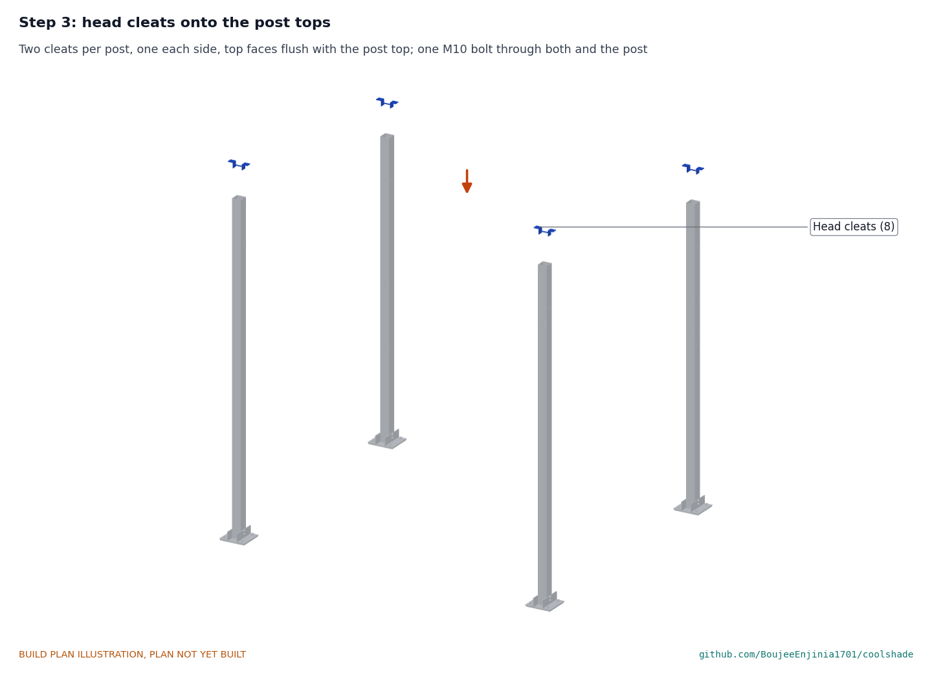
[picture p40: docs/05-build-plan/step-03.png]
Step 3


One cleat each side of each post top, flat legs flush with the top; one M10 bolt through both and the post, snug.

### Step 4: long beams onto the posts

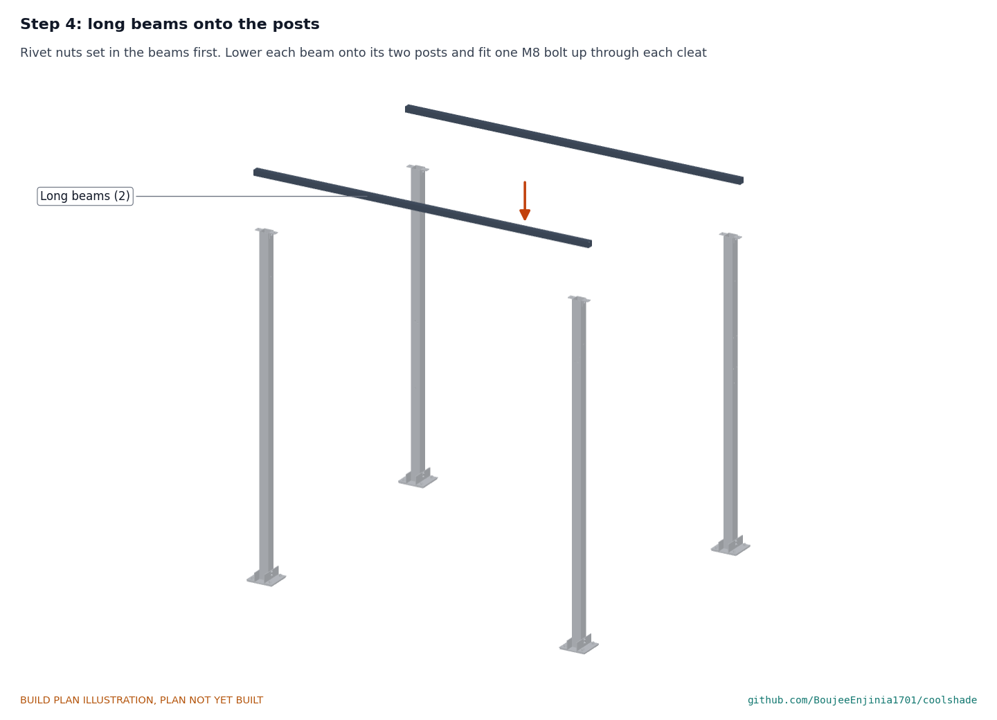
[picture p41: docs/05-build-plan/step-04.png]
Step 4


With the rivet nuts already set, two people lift each beam onto its two post tops, 100 mm overhanging each post, and fit the M8 bolts up through the head cleats. Check the beams are parallel (2,350 mm between centres at both ends), then tighten the head cleat bolts. **Hold point:** safety stop S3 for all work at height from here.

### Step 5: knee braces

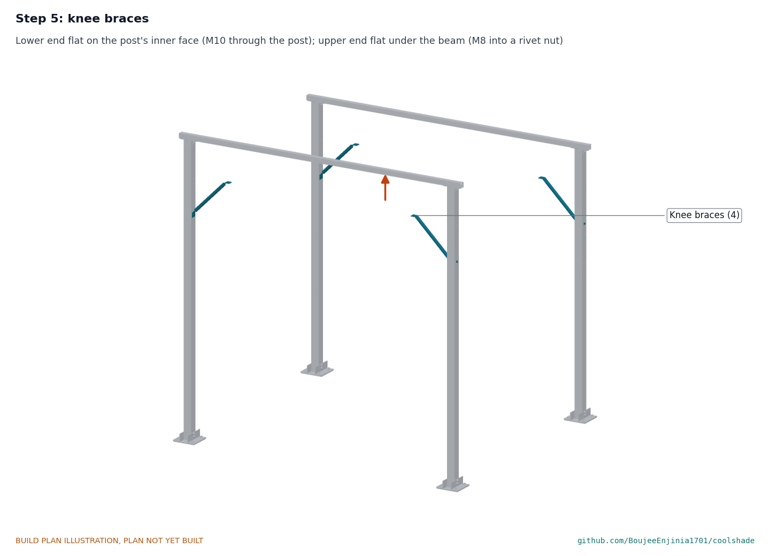
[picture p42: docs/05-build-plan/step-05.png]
Step 5


Lower end flat on the post's inner face with the M10 bolt through the post; upper end flat under the beam with the M8 bolt into its rivet nut. Tighten both.

### Step 6: frame cleats onto the long beams

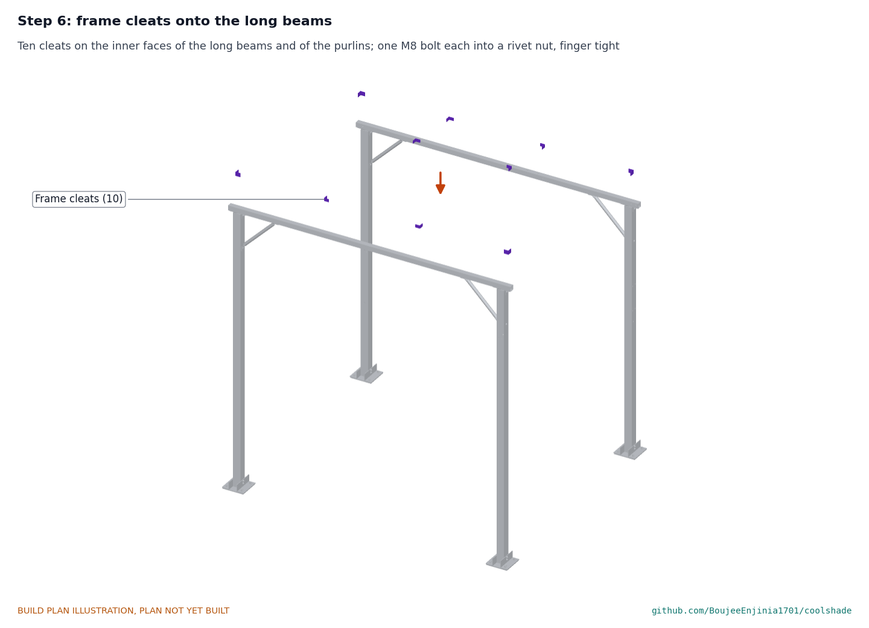
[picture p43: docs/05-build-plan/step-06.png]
Step 6


Fit the eight cleats on the long beams' inner faces (four 40 mm for the end beams, four 30 mm for the purlins), one M8 bolt each, finger tight. Fit the bearer's two 30 mm cleats on the purlins' inner faces now, on the bench.

### Step 7: end beams and purlins

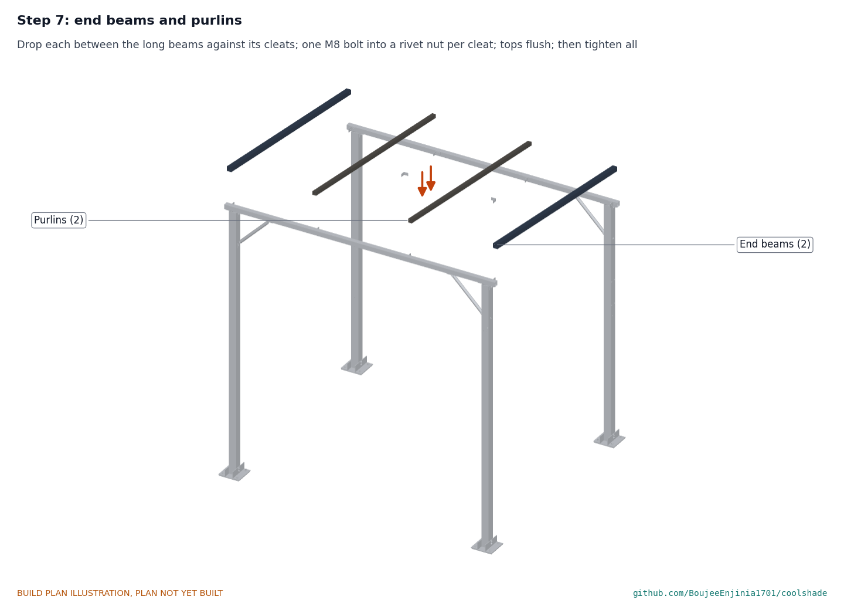
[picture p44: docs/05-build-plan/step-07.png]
Step 7


Drop each between the long beams against its cleats, ends flat on the beam faces, and fit one M8 bolt per cleat into the tube's rivet nut. Check the tops of the end beams and purlins are level with each other; then tighten all the frame cleat bolts.

### Step 8: panel bearer

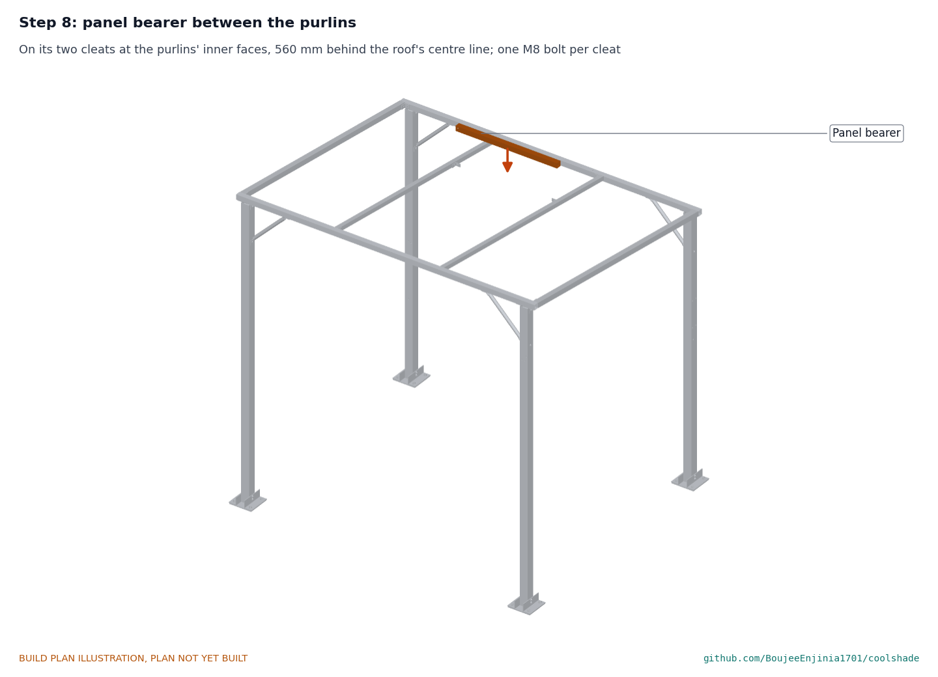
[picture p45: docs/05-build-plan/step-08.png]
Step 8


Fit the bearer between the purlins on its two cleats, its front face 1,685 mm behind the front beam's inner face; one M8 bolt per cleat.

### Step 9: mist line loop, clips, nozzles and vacuum breaker

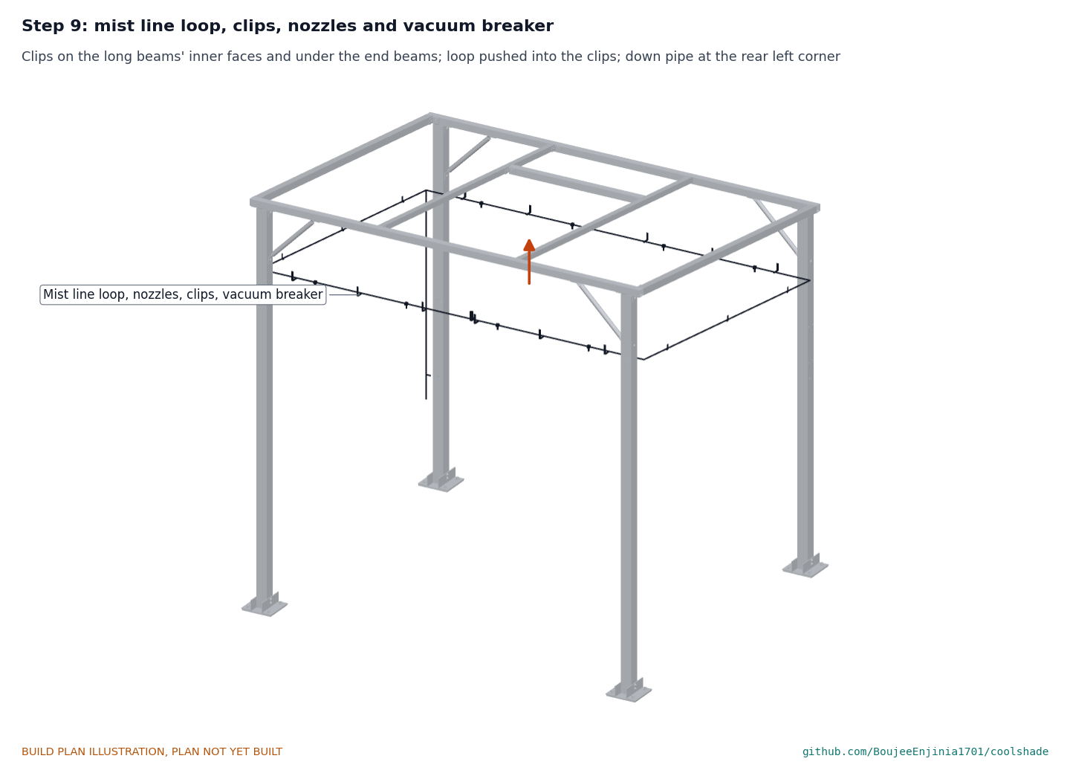
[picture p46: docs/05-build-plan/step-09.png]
Step 9


Screw the 18 hanger clips on with M5 screws: six on each long beam's inner face and three under each end beam. Push the line into the clips as one loop 70 mm inboard of the long beams and directly under the end beams; fit the eight nozzle tees (350 and 1,050 mm each side of centre on the front and rear runs), the vacuum breaker tee on the front run 150 mm right of centre, and the down pipe at the rear left corner. Set the clips on the rear run so the line falls slightly toward the down pipe. Leave the nozzle tips out until the first flush (safety stop S6).

### Step 10: L-feet and panel rails

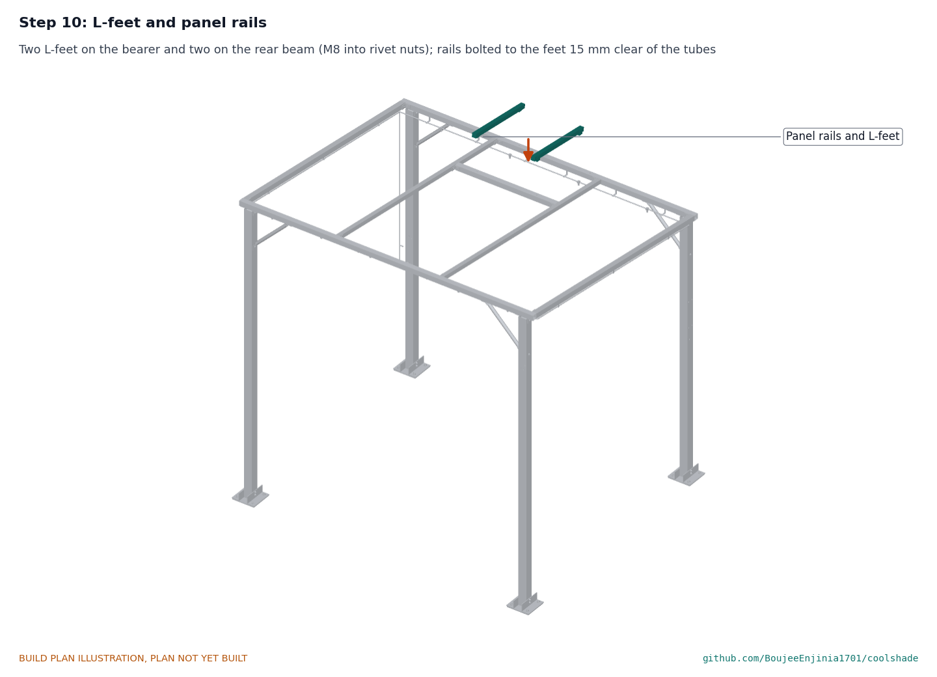
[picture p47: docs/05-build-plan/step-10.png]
Step 10


Two L-feet on the bearer and two on the rear beam, 300 mm each side of centre, on M8 bolts into the rivet nuts. Bolt the rails to the feet, parallel to the slope, 15 mm clear of the tubes (Figure 30).

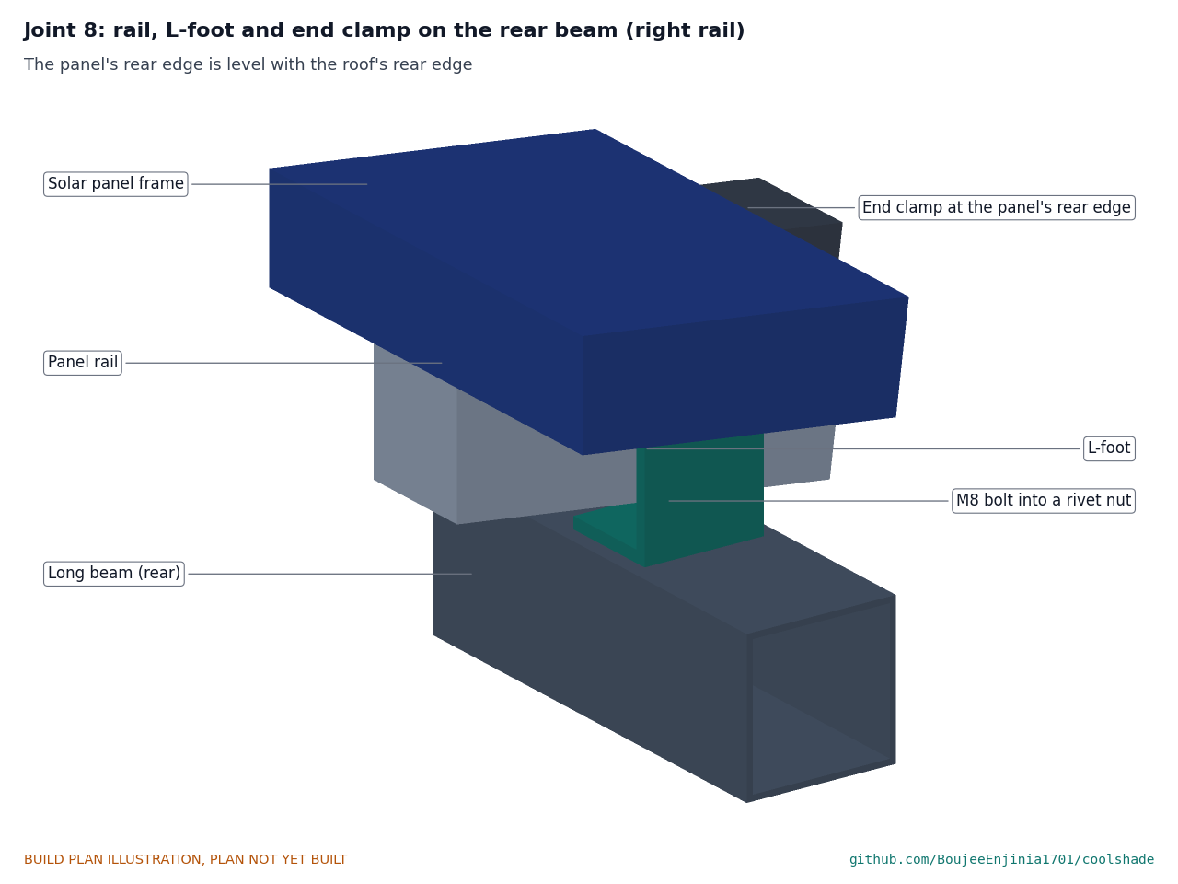
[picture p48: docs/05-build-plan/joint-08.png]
Figure 30. Joint 8: rail, L-foot and end clamp on the rear beam


*Figure 30. The rail stands on the L-foot 15 mm above the rear beam; the end clamp holds the panel's rear edge, level with the roof's rear edge.*

### Step 11: solar panel onto the rails

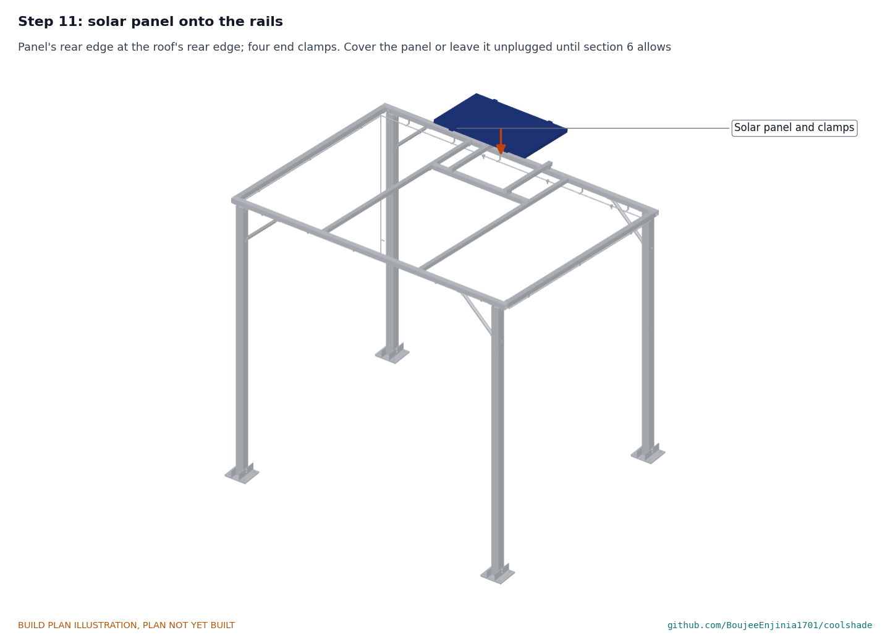
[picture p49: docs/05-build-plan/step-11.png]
Step 11


Two people lift the panel onto the rails, its rear edge level with the roof's rear edge, and fit the four end clamps. Cover the panel or leave its lead unplugged until section 6 allows.

### Step 12: enclosure rails and enclosure

Step 12

Bolt the rails to the rear right post's outer face with the M10 countersunk bolts, nuts on the inner face. Screw the enclosure to the rails with four M6 screws from inside, through its moulded holes. Fit the charge controller and controller board on the gear plate; the battery goes in later (stop S4), strapped to the floor with two straps.

Figure 31. Joint 10: enclosure on its rails

*Figure 31. The rails bolt through the post with flush heads; the box lies flat on them; the cable bundle leaves the post below the box and enters a gland.*

### Step 13: sensor arm, shield and PIR

Step 13

Bolt the arm to the street face of the front right post (two M8 through bolts, nuts inside); hang the shield under the arm's end on one M8 bolt. Fit the PIR's bracket under the middle of the front beam on two M5 screws into rivet nuts, the lens facing the waiting area.

Figure 32. Joint 11: sensor arm and shield

*Figure 32. The arm on the post's street face; the shield hangs 300 mm beyond the post, outside the roof.*

### Step 14: equipment plate, pump, filter and drain valve

Step 14

Bolt the plate to the rear left post's street face with two M10 bolts, nuts on the back face. Fit the pump, filter and drain valve on it. Connect the bottom of the down pipe to the valve's inlet and the tee to the pump outlet.

Figure 33. Joint 12: equipment plate

*Figure 33. The down pipe comes down beside the post into the drain valve; a tee takes the pump's outlet into it.*

Figure 34. Joint 9: mist line clip and nozzle

*Figure 34. The line hangs in clips on the beam's inner face, 70 mm inboard and 35 mm below the beam; nozzles point down.*

### Step 15: tank, stop cleats and strap

Step 15

Anchor the two stop cleats (one M10 anchor each) where Figure 2 shows, stand the tank against them, and pass the ratchet strap round the tank and the post at 400 mm. Tension it until the tank is pulled against the post.

Figure 35. Joint 13: tank strap and stop cleats

*Figure 35. The strap holds the tank to the post; the stop cleats stop it sliding away.*

### Step 16: cables and hoses

Step 16

*Cables run inside the posts and beams: the sensor and PIR cables through the front beam and the right end beam, the panel cable through the rear beam, all down inside the rear right post to the enclosure; the pump, valve and level switch cables through the rear beam and down the rear left post.*

Pull each cable through with a draw wire before connecting anything, a grommet at every hole and a drip loop below every gland. Connect the hoses tank to filter to pump with clamps. Wire the enclosure as Figure 28 with the battery out and its fuse out. **Hold point:** safety stops S4 to S7 before power or water.

### Step 17: shade fabric, last, in calm weather

Step 17

Only when forecast gusts are below 15 m/s. Lay the cloth over the frame from the street side, notch round the panel; lace every eyelet round the tube below it, working from the corners in, evenly tight. **Hold point:** safety stop S8.

## 5. First checks

These are the checks a TRL 4 test report would record; this plan only lists them. Requirement numbers are those of CSH-REQ-001.

*Table 2. First checks.*

| Check | Requirement | How | Pass when |
| --- | --- | --- | --- |
| Frame square, plumb and tight | R10, R14 | Diagonals, a level on every post, a spanner on every bolt | Diagonals within 5 mm; posts plumb within 5 mm over their height; nothing moves |
| Headroom | R2 | Tape from the slab to the brace ends, nozzles, clips and PIR | 2,200 mm or more everywhere inside the posts (2,223 mm expected at the rear braces) |
| Clear floor | R1 | Measure between the posts and mark the wheelchair space | 2.72 x 2.27 m clear; a 0.8 x 1.2 m space beside the bench |
| Cloth on and off | R10 | Time one person unlacing and relacing the cloth | 15 minutes or less each way |
| Line holds pressure | R7, R9 | Line flushed, nozzles fitted, pump run with the drain valve held closed | No leak at any fitting at 7 bar for 10 minutes |
| Nozzle flow | R7 | Collect one nozzle's spray in a bag for 60 s | 4 L/h, give or take 0.5, or record the value |
| Line drains | R9 | Stop the pump and time the flow at the valve outlet | The line empties within 5 minutes (about 30 s expected) |
| Activation logic | R6 | Bench test with the sensor warmed and dried, the PIR covered and uncovered, the float switch lifted | Mists only above 32 °C, below 60 % RH, with presence in the last 2 minutes and the tank above low level; stops within 60 s of any condition failing |
| Battery protection | R12 | With the battery in, check the 15 A fuse and the BMS cold-charge cutoff with the maker's method | Fuse rated 15 A; no charge current below 0 °C |
| Charging | R8 | Panel connected in sun; read the charge controller | It charges the battery at its LiFePO4 profile |
| Nozzle and filter service | R16 | Time removing and refitting one nozzle by hand and the filter cartridge | Nozzle 15 minutes or less without tools; filter 10 minutes or less |
| Heaviest lift | R17 | Weigh a front post before fitting | 40 kg or less (21 kg expected) |
| No camera or microphone | R11 | Inspect the parts fitted | None present |

## 6. Safety stops

Stop at each point. Carry on only when everything listed is true.

- **S1. Before drilling the slab.** The site owner's written permission; the slab is checked for buried services with a scanner; the slab and anchor type are confirmed for about 2.8 kN factored per anchor by someone able to judge it; dust masks and eye and ear protection on.
- **S2. Before standing the posts.** Two people per post; props ready; nobody under a post being raised; anchors set and their nuts on.
- **S3. Before any work at height.** Stable ladders or a platform on level ground, a second person at the foot; beams lifted by two people; tools on lanyards; the area under the work coned off.
- **S4. Before the battery goes in.** Battery voltage about 12.8 to 13.4 V, no swelling or damage, the maker's datasheet in hand; 15 A fuse out; polarity of every power lead checked with a meter, not by colour.
- **S5. Before the battery fuse goes in.** No short from any rail to the enclosure; the pump and valve drivers off; panel unplugged. First charge attended, lid open, battery temperature checked; stop if it passes 45 °C.
- **S6. Before the line is pressurized.** Potable water only; every fitting pushed fully home and clipped; nozzles out for the first flush; eye protection on; the drain valve opens when the pump stops. Never open a fitting until the line is depressurized.
- **S7. Before misting with anyone nearby.** The tank cleaned, disinfected and filled with fresh potable water; the line drained after every run; a written hygiene routine (daily drain and refill, weekly disinfection) and a named responsible person (at a market lane, the market operator's manager); no misting if any of this has lapsed.
- **S8. Before the cloth goes on.** Forecast gusts below 15 m/s (54 km/h) for the time it will be on; every frame bolt tight; someone named to take it off before storms.
- **S9. Before any public use (outside this plan).** An engineer's check of the slab and anchors at the site; the asset owner's permission; a hygiene plan accepted by the environmental health authority of the city or county where the site stands (a market lane is the first site type); signs that the mist is not drinking water or a medical service.

## 7. Tools, skills and workspace

**Tools.** Metal cutting saw or angle grinder with cutting discs; bench or pillar drill and a hand drill, drills 5 to 18 mm, a step drill, countersink, M6 tap; hammer drill and masonry bits for the M16 and M10 anchors; hand rivet nut tool for M8 and M5 steel rivet nuts; heavy bench vice and a length of tube for bending the brace ends; files and a deburring tool; spanners and sockets 8 to 24 mm and a torque wrench; spirit level, plumb line, 5 m tape, chalk line and string; two stable stepladders or a mobile platform; ratchet strap; wire strippers, ferrule crimper, soldering iron and multimeter; a bucket and stopwatch for the nozzle check.

**Skills.** No certified trade is needed for the frame: marking out, cutting, drilling and bolting steel, setting rivet nuts and anchors, and safe work at height with a second person. Electrical work is all extra-low voltage (12.8 V nominal, under 22 V from the panel); the battery needs care. Anchoring to a public slab and the water hygiene plan need the site owner's and the health authority's agreement.

**Workspace.** A bench with a vice for the steel parts; a level working area at the site at least 5 x 4 m that can be coned off; shade and water for the team; a dry, non-combustible place to keep and first charge the battery.

**Personal protective equipment.** Safety glasses, hearing protection and gloves for cutting and drilling; a dust mask for drilling concrete; safety boots; hard hats while the frame is overhead; no gloves near a turning drill.

## 8. Where the numbers come from

- Model and constructability checks: `cad/src/model.py` (`python cad/src/model.py --check`, 117 checks); STEP and STL exports in `cad/step/` and `cad/stl/`.
- Pictures: `cad/src/build_plan_media.py`, using `.kit/build_views.py`; written to `docs/05-build-plan/` and `cad/drawings/CSH-DWG-101` to `CSH-DWG-116`.
- General arrangement: `cad/drawings/CSH-DWG-001.pdf`, Rev P4.
- Calculations: `docs/04-calcs/01-sizing.md` (CSH-CAL-001 v0.3) and `docs/04-calcs/sizing.py`; headroom [B2], [B3], mist line [C7], wind and anchors [G13], [G14], rivet nuts [G15], masses [G1], [H1], fixings [H2], cost [J1].
- Bill of materials: `bom/bom.csv`.
- Decisions: `docs/decisions/0003-design-for-construction.md` (CSH-DDR-003), with CSH-DDR-001 and CSH-DDR-002; open items in `docs/06-design-decisions.md` (CSH-DEC-001).
- Requirements: `docs/03-requirements.md` (CSH-REQ-001 v0.5).

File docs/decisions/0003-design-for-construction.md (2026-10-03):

---
doc_id: CSH-DDR-003
title: CoolShade design for construction
project: CoolShade
doc_type: Design decision record
version: "0.4"
status: Draft
date: '2026-10-02'
author: Amish Chadha
license: CERN-OHL-S-2.0
revisions:
- version: "0.1"
  date: '2026-09-30'
  author: Amish Chadha
  change: Changes that make the concept physically buildable, with the reason for each; made under Amish's 2026-09-30 instruction to make the design physically buildable; open for his review
- version: "0.2"
  date: '2026-10-01'
  author: Amish Chadha
  change: Budget treated as a value-engineering target, with cost question A1 replaced by the register's Value engineering section
- version: "0.3"
  date: '2026-10-02'
  author: Amish Chadha
  change: "A2 decided by Amish on 2026-10-02 as recommended (rivet nut tool and bench vice added to R14)"
- version: "0.4"
  date: '2026-10-02'
  author: Amish Chadha
  change: "Changes P1 to P16 (Table 1) and their knock-on changes (Table 2) accepted by Amish on 2026-10-02"
---

# 0003: Design for construction

- **Date:** 2026-09-30
- **Status:** accepted. Amish, 2026-10-02: "APPROVED: Design-for-construction changes in 10 repos (CityTwin, CoolShade, PalletPilot, Heliolite, PotholeLog, EarthPress, ReadyKit, CellCheck, CargoMule and ThermaCart)". This covers the changes P1 to P16 in Table 1 and their knock-on changes in Table 2, made under Amish's 2026-09-30 instruction to make the design physically buildable, and is recorded in the design decisions register (CSH-DEC-001). The item in Table 3 (A2) was decided as recommended earlier the same day: Amish, 2026-10-02: "i approve your recommendations for all 555 open decisions." It is recorded in the register too.

## Context

On 2026-09-30 Amish asked for every repo to have an illustrated build plan that shows how each component is made and how it fits the next, and wrote: "If you are realising that the design cannot be built as per concept - fix the design assumptions to match and be physically feasible as you draw the illustrations." The TRL 3 model of CSH-DDR-002 was a massing model: it showed what CoolShade does, but most of its parts met as overlapping solids with no fixing, and some could not be made or fitted at all. Checking it part by part found the problems P1 to P16 below.

The changes keep what CoolShade does and its pitch: a bolted four-post canopy, 3.0 x 2.4 m in plan with the same roof heights and slope, the same shade cloth, 100 W panel, 25 Ah battery, controller, sensors, 7 bar pump, 120 L tank, eight nozzles, drain valve and vacuum breaker, the same activation rules and the same safety case (fabric off above 15 m/s, drain after every session, 12 V only). Every change is in `cad/src/model.py`, which now runs 117 constructability checks with build123d (`python cad/src/model.py --check`): every pair of the 61 modelled parts that come near each other is tested for overlap, every joint for contact, and the headroom and the sensor shield's height are measured. All 117 pass.

## Decision

*Table 1. Changes made to the model, the BOM and the calculations.*

| # | Problem in the concept | Change made | Why this way |
| --- | --- | --- | --- |
| P1 | The shade cloth (3.0 x 2.4 m) ran 125 mm past the long beams at the street and rear edges and 75 mm past the end beams, with nothing under its edges to lace or tension it to. | Posts moved out across the sidewalk from 2,100 to 2,350 mm between centres, so the long beams sit on the post tops at the roof's street and rear edges; end beams moved from the posts to the roof ends, 1,475 mm each side of centre. The cloth is laced over the frame, every eyelet round the tube below it. | Keeps the 3.0 x 2.4 m roof and its 7.2 m² of shade (R1). Moving the posts out is simpler than adding outriggers, and widens the clear floor from 2.02 to 2.27 m. |
| P2 | The long beams, end beams and post tops met as overlapping solids at the corners, with no brackets. | The long beams sit on the posts; the end beams, purlins and panel bearer are cut to butt against the beams' inner faces and are held by 50 x 50 x 5 mm angle cleats, one M8 bolt into each tube. | Every joint is face to face and bolted; one cleat size for the whole roof. |
| P3 | The long beams were tilted with the 7.1° roof plane, which a square tube cannot do on a square-cut post top. | The long beams are horizontal and square; only the end beams and purlins slope. Their ends are cut 7° off square so they stand upright against the beam faces. | The cloth still lies on a 7.1° plane: the long beams' top edges and the sloping tubes' tops meet it within 4 mm. |
| P4 | The post tops had no fixing to the beams. | Two head cleats per post (50 x 50 x 5 mm angle, 46 mm long), one on each side face, flat leg flush with the square-cut post top: one M10 bolt through both cleats and the post, one M8 bolt up into a rivet nut in the beam's underside per cleat. | No welding (R14), nothing on the beam tops under the cloth. |
| P5 | Each post stood on its base plate with no fixing. | Two base cleats per post (75 x 75 x 6 mm angle, 220 mm long), one each side: two M12 bolts through cleat, post and cleat; the four M16 anchors pass through the cleats' flat legs and the plate. | Bolted post base without welding, using the anchors the concept already had on the same 160 mm square. |
| P6 | The knee braces were solid rods whose ends ran into the post and beam, with no fixing. | 32 mm tube, 581 mm long, both ends flattened in a vice and bent 45°: the lower end bolted flat on the post's inner face (M10 through the post), the upper end flat under the beam (M8 into a rivet nut). The bends are 350 mm down the post and along the beam (was 400 mm). | Flattened ends are the simplest bolted brace end. The shorter brace keeps the bottom of its flattened end at 2,223 mm, above R2's 2,200 mm. |
| P7 | The panel rails floated 15 mm above the purlins and passed through the cloth, the panel overlapped its rails, and with the panel on top of the cloth the cloth could not be taken off before storms (R10). | The panel moves to the rear edge of the roof on two rails standing on four L-feet: two on a new 50 x 50 x 2 mm panel bearer between the purlins and two on the rear long beam. The cloth has a 1,020 x 670 mm notch under the panel, laced round the bearer and the purlins; the panel shades the notch. The purlins move from 450 to 530 mm each side of centre to frame the notch. | The cloth comes off without touching the panel; the panel stays up in a storm. The panel's shade replaces the cloth's under the notch, so the shaded area is unchanged. |
| P8 | The enclosure floated against the rear right post with no fixing, and the battery and MPPT were solids inside a solid box. | Two 40 x 6 mm rails through-bolted to the post's outer face with M10 countersunk bolts; the enclosure screws to the rails from inside through its moulded mounting holes. Battery on the enclosure floor, MPPT and controller board on the maker's gear plate, three cable glands underneath. | The enclosure stays sealed and lies flat on the rails clear of the post. |
| P9 | The sensor shield's plates floated with gaps between them; the arm was a rod with no fixing whose tip ran through the shield; with the arm at 2.30 m the lowest plate hung at 2.25 m beside a footway. | A bought multi-plate shield with its own top plate and spacers, hung by one M8 bolt under the end of a 40 x 40 x 4 mm angle arm; the arm is bolted to the street face of the front right post with two M8 through bolts, its top 2,420 mm up. | The shield's lowest plate is at 2,266 mm, still outside the roof and the mist zone. |
| P10 | The PIR sensor touched the front beam with no fixing. | A small bracket on two M5 rivet nuts under the front beam. | |
| P11 | The pump floated 10 mm off the rear left post, the filter and drain valve floated, and nothing joined the down pipe to the drain valve (REVIEW 2026-09-26, items 2 and 3). | A 320 x 630 x 3 mm equipment plate bolted to the street face of the rear left post carries the pump, filter and drain valve. The down pipe ends in the drain valve, the system's low point, with a tee to the pump outlet. | One plate, two bolts through the post; the valve stays at the low point so the line drains. |
| P12 | The tank overlapped the rear left post and its base by about 30 mm; the "two small anchors" had nothing to hold. | The tank moves to 350 mm in from the post along the curb and 355 mm toward the street, clear of the post base. A ratchet strap goes round the tank and the post at 400 mm, and two stop cleats with one M10 anchor each stop the tank sliding away from the post. | The strap still holds an empty tank against the 30 m/s gust [G12]. |
| P13 | The mist line had no supports, and the supply hose bypassed the filter (REVIEW 2026-09-26, item 1). | The loop runs 70 mm inboard of the long beams and directly under the end beams, held by 18 hanger clips on M5 rivet nuts; hoses run tank to filter to pump. | Clear of the posts, braces and cleats by at least 26 mm. |
| P14 | The cables ran as rods through the post and beam walls and through the enclosure. | Cables run inside the posts and beams, through 12 mm grommeted holes, into the enclosure through three glands underneath. | Tidy, out of reach and protected from the sun. |
| P15 | Parts needed but missing: a tank level sensor for R6's "tank above its low level" rule (CSH-DDR-001, D2), and a way to carry the sensor's I2C signal about 7 m. | BOM line 13 adds a low-level float switch with its cable; line 9 adds an I2C bus extender pair. | Needed for the decided control rule; I2C alone is not reliable over 7 m. |
| P16 | Through bolts into the closed beams would put nuts under the cloth and crush the tubes. | Every bolt into a beam goes into a steel rivet nut (36 M8, 20 M5). | Nothing stands proud where the cloth runs. The largest pull on one M8 rivet nut is about 0.16 kN factored [G15]. |

*Table 2. Knock-on changes.*

| Item | Change | Reason |
| --- | --- | --- |
| Posts | Front 2,902 mm and rear 2,608 mm (were about 2.89 and 2.62 m) on a 2,800 x 2,350 mm grid. Heaviest part a front post, 21.0 kg (was 22.0 kg with its brace) [H1]. | P1, P4 |
| Space and headroom | Clear floor 2.72 x 2.27 m: room for 8 standing and 3 seated with the wheelchair space (was 7) [A3]. Lowest point overhead 2,223 mm (was 2,234 mm) [B2]. Nozzle tips 2,559 mm rear, 2,835 mm front (were 2,584 and 2,829 mm) [B3]. Droplet size that stays clear of heads on the humid edge about 80 µm (was 81 µm) [D3]. | P1, P6, P13 |
| Mist line | 11.91 m, 0.40 L, drains in about 30 s (was 10.96 m, 0.36 L, 27 s) [C7]. | P1, P13 |
| Structure | Steel 167 kg (was 143 kg before brackets and bolts) [G1]. Fabric off at 30 m/s: posts 0.14, panel bearer 0.02, purlins 0.07 (were 0.15), rear beam from the panel feet 0.11; anchors about 2.8 kN factored, unchanged [G13]. Fabric on at 15 m/s: long beams 0.88, unchanged [G14]. | P1, P5, P7 |
| Fixings | 79 bolts and anchors, 36 of them M8 into rivet nuts (was about 48) [H2]. Two added hand tools: a rivet nut tool and a bench vice. | P2 to P16 |
| Cost | BOM lines 1 to 5, 8 to 10, 12, 13 and 16 updated: $882.00 (was $773.00), $107 (13.8 %) over the $775 value-engineering target (`budget_usd`). R13 moves from at risk to over the value-engineering target. `budget_usd` is not changed; savings worth trying are in the register's Value engineering section. | Parts added for construction |
| Drawings | General arrangement CSH-DWG-001 Rev P4; making sketches CSH-DWG-101 to 116 added. | Follows the model |
| Documents | CSH-CAL-001 v0.3, CSH-PRC-001 v0.5, CSH-REQ-001 v0.5, BOM and BOM notes. | Follows the model |
| Concept media | Hero, exploded view, blueprint and 3D viewer regenerated from the new model. | Follows the model |

*Table 3. Proposed, then decided by Amish on 2026-10-02.*

| # | Question | Options | Recommendation |
| --- | --- | --- | --- |
| A2 | R14 lists the tools as a drill, angle grinder, spanners and a ladder; the constructable design adds a hand rivet nut tool and a bench vice (for the brace ends). | (a) add both to R14's tool list; (b) use through bolts instead of rivet nuts, which puts nuts under the cloth and can crush the tubes. | (a). **Decided 2026-10-02: (a)**; R14 now lists both tools (CSH-REQ-001). |

## Consequences

- `design_state: constructable` in `project.yaml`. The build plan CSH-BLD-001 shows every component and step in pictures generated from the model (`cad/src/build_plan_media.py`); decisions are recorded in the design decisions register CSH-DEC-001.
- Requirement status (CSH-CAL-001 v0.3): 1 over its value-engineering target (R13 cost), 2 at risk (R9 water hygiene, R16 nozzle scaling), 1 not verifiable at TRL 3 (R5 wetting), 13 met. Before this record it was none not met, 3 at risk (R9, R13, R16), 1 not verifiable and 13 met.
- The photoreal renders (`media/render-hero.png`, `render-exploded.png`, `render-detail.png`), `media/card.png`, `media/social-preview.png` and the appearance model `cad/src/product_model.py` still show the concept: posts on the 2.1 m grid, the panel in the middle of the rear half on top of the cloth, the tank against the post and the hose bypassing the filter. They need updating on Amish's Mac, where Blender is.
- Nothing here authorizes building, buying or testing; TRL 4 stays on hold by Amish's instruction.

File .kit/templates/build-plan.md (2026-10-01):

---
doc_id: PRJ-BLD-001
title: Project prototype build plan
project: Project name
doc_type: Build plan
version: "0.1"
status: Draft
date: YYYY-MM-DD
author: Amish Chadha
license: CERN-OHL-S-2.0
revisions:
  - version: "0.1"
    date: YYYY-MM-DD
    author: Amish Chadha
    change: First build plan; design made constructable
---

# Project prototype build plan

**Plan, not yet built.** How to build the first proof-of-concept prototype, component by component. Building and testing to it is TRL 4 work. Decisions still to be made are kept in the design decisions register (`docs/06-design-decisions.md`), not here.

## 1. What you are building

Every component, pulled apart and numbered in build order

One short paragraph: what the prototype is, how many components, which are made and which are bought, and the main ways they are made.

## 2. What changed to make it buildable

| Component | The concept had | The buildable design has | Why |
| --- | --- | --- | --- |

## 3. Making the components

### 3.1 Component name

Making sketch

**What it is and what it is made from.**

**How to make it.**

1. Mark out ...
2. Cut ...

**How it fits the parts next to it.**

Close-up of the joint

**Check before moving on.**

## 4. Putting it together

### Step 1: ...

Step 1

## 5. First checks

| Check | Requirement | How | Pass when |
| --- | --- | --- | --- |

## 6. Safety stops

## 7. Tools, skills and workspace

## 8. Where the numbers come from

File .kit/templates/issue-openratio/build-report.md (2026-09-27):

---
name: Build report
about: Tell us what happened when you built, printed or tested part of this design
title: "Build report: "
labels: build-report
---

This is a research and educational prototype, not a medical device. It is a TRL 3 concept and is not released for fabrication. If you build any part of it, you do so at your own risk. Reports help everyone.

**What you built** (part, sub-assembly or test)

**Materials, tools and settings**

**What worked**

**What did not work, with photos or measurements if you have them**

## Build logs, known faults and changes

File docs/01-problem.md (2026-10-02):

---
doc_id: CSH-PRB-001
title: CoolShade problem statement
project: CoolShade
doc_type: Problem statement
version: "0.5"
status: Draft
date: '2026-10-02'
author: Amish Chadha
license: CERN-OHL-S-2.0
revisions:
- version: "0.1"
  date: '2026-09-25'
  author: Amish Chadha
  change: Initial scaffold
- version: "0.2"
  date: '2026-09-25'
  author: Amish Chadha
  change: Populate to TRL 2 (problem, users, context, constraints, prior work, open questions)
- version: "0.3"
  date: '2026-09-25'
  author: Amish Chadha
  change: TRL 3 update; budget constraint stated against the proposed figure, humid edge of the misting window, open questions aligned with CSH-DDR-001 and CSH-CAL-001
- version: "0.4"
  date: '2026-09-25'
  author: Amish Chadha
  change: Recommendations accepted by Amish (DDR-002)
- version: "0.5"
  date: '2026-10-02'
  author: Amish Chadha
  change: "First site type and partner decided by Amish on 2026-10-02; first candidates named"
---

# CoolShade problem statement

People waiting outdoors in extreme heat have nowhere to cool down, and public cooling is rarely where they wait. Bus stops, market lanes, clinic and ration queues and school gates put people in full sun for 10 to 60 minutes at a time, often at midday, and the people who wait longest are often those with the fewest alternatives.

## The problem

Heat is a leading weather-related cause of death. WHO estimates about 489,000 heat-related deaths each year between 2000 and 2019, 45 % of them in Asia and 36 % in Europe, and notes that the urban and rural poor are often disproportionately exposed, with informal settlements often hotter than other urban areas ([WHO](https://www.who.int/news-room/fact-sheets/detail/climate-change-heat-and-health)). In one summer, 2022, an estimated 61,672 people died of heat across 35 European countries ([Ballester et al., *Nature Medicine*, 2023](https://www.nature.com/articles/s41591-023-02419-z)).

Cities make it worse where people stand. The US EPA reports urban daytime temperatures about 1 to 7 °F (about 0.5 to 4 °C) above outlying areas ([US EPA](https://www.epa.gov/heatislands/learn-about-heat-islands)). For a person in the sun, radiant heat from the sun and hot surfaces matters as much as air temperature. In Tempe, Arizona, measurements at 159 locations found that even lightweight shade such as umbrellas and shade sails cut the daytime mean radiant temperature by about 17.3 °C ([Middel et al., *BAMS*, 2021](https://journals.ametsoc.org/view/journals/bams/102/9/BAMS-D-20-0193.1.xml)).

Cooling centers and air-conditioned shelters help people who can travel to them, but they are not where people must wait. Many stops and market spots have no shade at all, and where there is shade it does nothing about hot, still air. Commercial misting systems exist, but they are usually mains-powered, high-pressure installations for restaurants and theme parks, run on timers regardless of humidity or occupancy, and are not designed for unattended public sites without power.

## Users and context

| User | Need | Context |
| --- | --- | --- |
| Transit riders waiting at stops | Shade and some relief from hot air for 5 to 30 min, without getting wet | Curbside stops, often with no power or water connection |
| Market traders and shoppers | Cooler place to stand and sell during the midday peak | Open-air markets, informal vendors |
| People in queues | Relief during long waits at clinics, offices, food and water distribution | Temporary or semi-permanent sites |
| Outdoor workers | Shaded, cooled rest spot close to work | Street vendors, traffic staff, delivery riders |
| City, transit or market operator | Low-maintenance unit that is safe, uses little water and no grid power, and can be moved | Asset owner responsible for hygiene, permits and inspection |
| Community groups and schools | A shade they can build and maintain themselves | School gates, community spaces |

Heat-vulnerable people include older adults, young children, pregnant people, people with chronic illness and outdoor workers ([WHO](https://www.who.int/news-room/fact-sheets/detail/climate-change-heat-and-health)). The design must work for them, including wheelchair users.

## Operating environment

- Hot seasons with air temperatures of 32 to 45 °C and strong sun; the design case is 38 °C at 25 % relative humidity (hot and dry) with a check at 35 °C and 60 % (hot and humid). The wettest air in which the unit still mists is 32 °C at 60 %, the humid edge used for the wetting check in CSH-CAL-001.
- Misting only helps when the air can absorb water. In hot, humid air it adds little cooling and wets people, so the unit must not mist then.
- Dust, rain, hard water, vandalism and theft; public sites with no staff present most of the time.
- Wind storms. The shade fabric can act as a sail, and on the conservative TRL 3 calculation it must come off before gusts of about 16 m/s (58 km/h). The fabric is fitted only when forecast gusts are below 15 m/s (54 km/h) (CSH-CAL-001, CSH-DDR-002).

## Constraints

- Garage-buildable prototype, about $775 USD in parts (`budget_usd`, set by Amish on 2026-09-25, CSH-DDR-002; it was $700). The parts cost is $773 (CSH-CAL-001).
- Off-grid: solar powered, 12 V DC only, no mains connection needed.
- Water from a refillable tank; mains water connection optional where local rules permit, with backflow prevention.
- Bolted steel frame; no welding required.
- Water hygiene is a public health requirement. *Legionella* grows in water at 20 to 50 °C (optimal 35 °C) and spreads by inhaled aerosols ([WHO](https://www.who.int/news-room/fact-sheets/detail/legionellosis)). A misting system in a hot climate is exactly such an aerosol source.
- Privacy: presence detection only (passive infrared). No camera or microphone; no images or audio are recorded or leave the device.
- Installation on public land needs the asset owner's permission.

## Out of scope

- Air conditioning or enclosed, cooled shelters.
- High-pressure (about 70 bar) mains-powered misting.
- Drinking water supply. The tank water is not for drinking.
- Heat warnings or health advice. CoolShade provides shade and local cooling only.

## Prior work

- Shade: the Tempe shade study above measured large radiant heat reductions from shade sails and structures ([Middel et al., 2021](https://journals.ametsoc.org/view/journals/bams/102/9/BAMS-D-20-0193.1.xml)).
- Misting: a systematic review of water mist spray for outdoor cooling covers technologies, methods and impacts ([Ulpiani, *Applied Energy*, 2019](https://doi.org/10.1016/j.apenergy.2019.113647)). Field evaluations include an outdoor mist fan ([Farnham, Emura and Mizuno, *Building Research and Information* 43(3), 2015](https://doi.org/10.1080/09613218.2015.1004844)) and a shade sail and mist-spray hybrid in a school courtyard ([Zhao et al., SSRN preprint, 2023](https://doi.org/10.2139/ssrn.4627041)).
- Lab siblings: HeatMap Node measures street-level heat stress and can identify where shade is most needed. FieldNode is the lab's shared solar and LoRaWAN sensor core, which CoolShade could use for an optional status link.

No open, solar-powered, humidity- and occupancy-controlled misting shade for public waiting spots was found in this review; that is the gap CoolShade targets.

## Open questions

- Which sites to start with (bus stop, market, clinic queue) and through which partner? Decided 2026-10-02: a market lane first, with the market operator as co-design partner, in a hot, dry city. The first candidate to approach is a farmers' market operator in the Phoenix area, with Arizona State University's urban heat researchers as the candidate measurement partner; nothing is agreed with either (CSH-DEC-001).
- Is misting acceptable to users at all, given concerns about wet clothes, hair and hygiene? To be asked in co-design.
- Who refills the tank and flushes the lines, and can they visit daily on hot days? CSH-CAL-001 assumes a daily drain-and-refill of about 95 L.
- What local rules apply to public misting (water hygiene, permits, mains backflow)?

## User research and co-design

This design is for communities the author is not part of, so requirements come from the people who will use it.

- [ ] Identify a local partner organization (Helpful Engineering network, NGO or university)
- [ ] Run co-design sessions with intended users; record who, where and what was learned
- [ ] Validate load, distance, terrain and cost assumptions in the field
- [ ] Revise requirements (REQ) from findings before freezing the design

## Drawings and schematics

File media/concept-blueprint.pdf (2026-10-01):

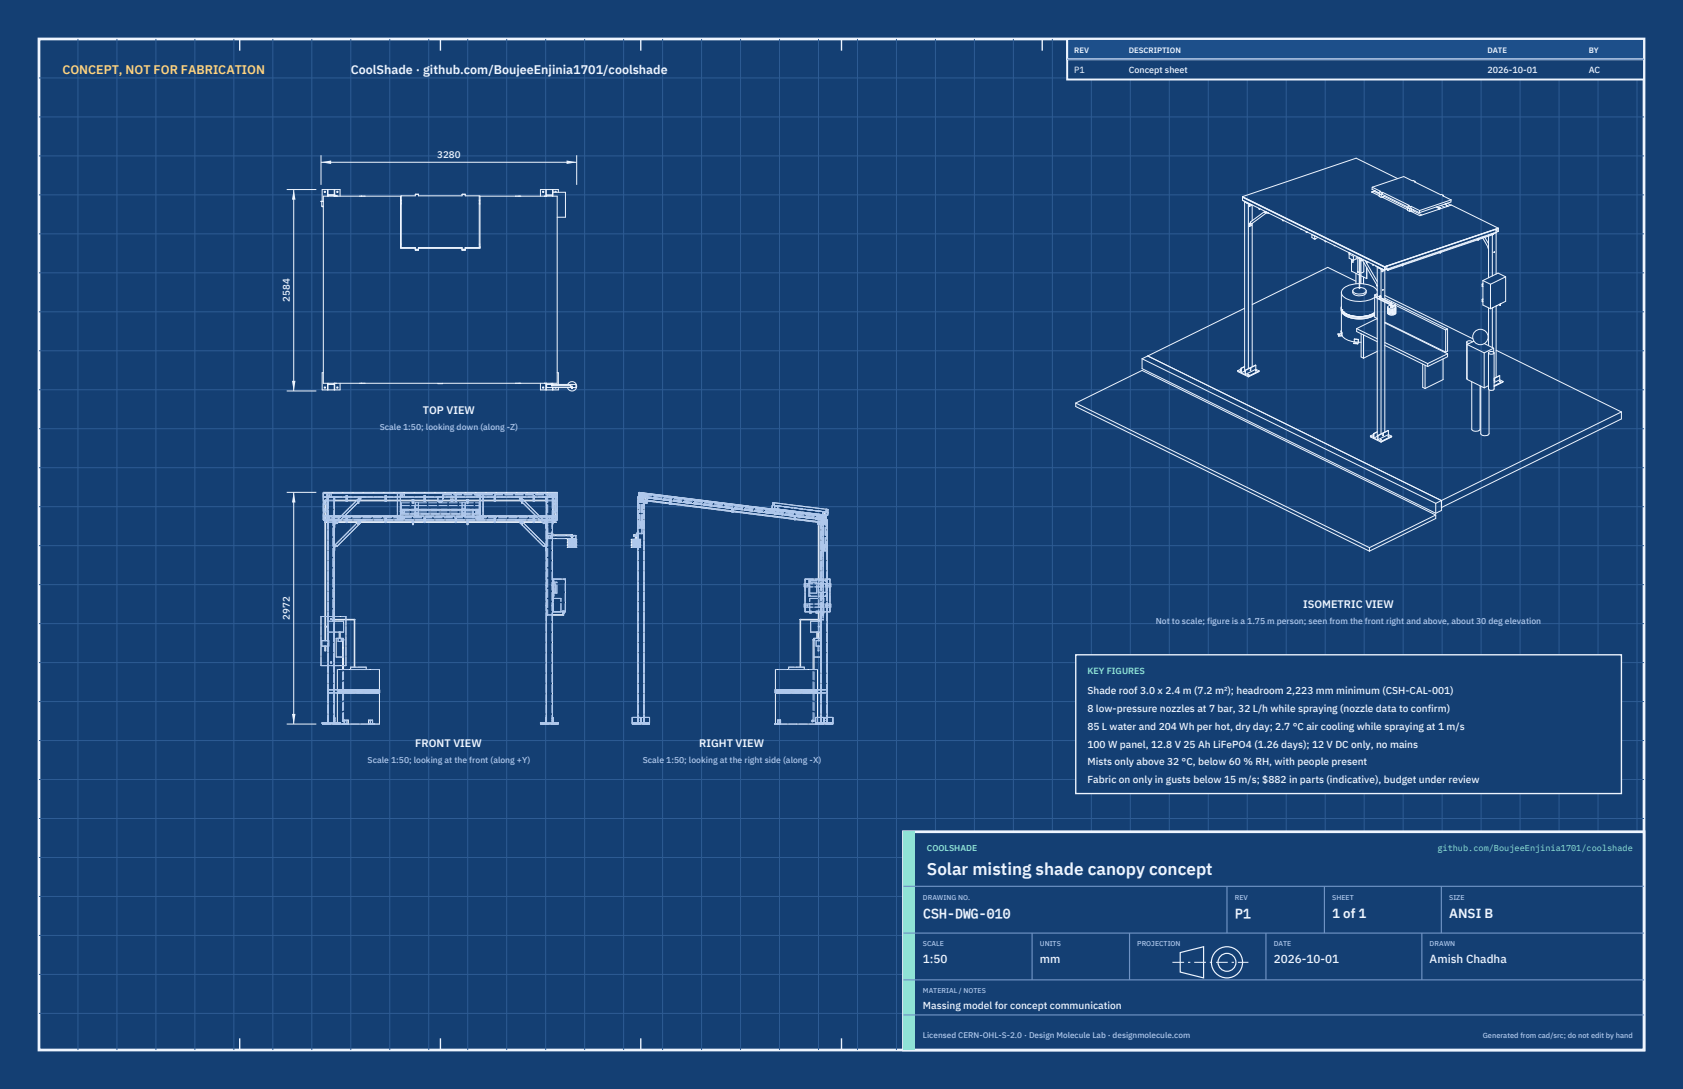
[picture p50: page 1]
CONCEPT, NOT FOR FABRICATION; CoolShade · github.com/BoujeeEnjinia1701/coolshade; FRONT VIEW; TOP VIEW; RIGHT VIEW; ISOMETRIC VIEW; REV; DESCRIPTION; DATE; Concept sheet; COOLSHADE; github.com/BoujeeEnjinia1701/coolshade; DRAWING NO. CSH-DWG-010; REV P1; SHEET 1 of 1; SIZE ANSI B; SCALE 1:50; UNITS mm; PROJECTION; DRAWN Amish Chadha; Licensed CERN-OHL-S-2.0 · Design Molecule Lab · designmolecule.com; Generated from cad/src; do not edit by hand

Scale 1:50; looking down (along -Z)

Not to scale; figure is a 1.75 m person; seen from the front right and above, about 30 deg elevation

KEY FIGURES
Shade roof 3.0 x 2.4 m (7.2 m²); headroom 2,223 mm minimum (CSH-CAL-001)
8 low-pressure nozzles at 7 bar, 32 L/h while spraying (nozzle data to confirm)
85 L water and 204 Wh per hot, dry day; 2.7 °C air cooling while spraying at 1 m/s
100 W panel, 12.8 V 25 Ah LiFePO4 (1.26 days); 12 V DC only, no mains
Mists only above 32 °C, below 60 % RH, with people present
Fabric on only in gusts below 15 m/s; $882 in parts (indicative), budget under review

Scale 1:50; looking at the front (along +Y)

Scale 1:50; looking at the right side (along -X)

Solar misting shade canopy concept

MATERIAL / NOTES
Massing model for concept communication

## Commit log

2026-09-25 Initial scaffold: standard open hardware layout, CERN-OHL-S v2 + MIT licenses
    Claude-Session: https://claude.ai/code/session_01XuhhSU4W6fYhgCfURbrkut
    [bom.csv]
2026-09-26 Populate to TRL 2: problem, requirements, precis, concept media, BOM and README use cases
    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
    [bom.csv]
2026-09-26 Advance to TRL 3: DDR-001, CAL-001 sizing, parametric model with STEP/STL, GA drawing, priced BOM; TRL 4 on hold
    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
    [bom.csv, coolshade-assembly.step, coolshade-assembly.stl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]
2026-09-26 Accept all recommendations (DDR-002), switch footer to designmolecule.com, add README write-up with new inspiration point
    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
    [bom.csv, coolshade-assembly.step, coolshade-assembly.stl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]
2026-09-27 Product appearance model and photoreal renders
    Adds cad/src/product_model.py (appearance model for renders only, all main
    dimensions from model.py) and Blender renders in media/render-*.png,
    captioned with the project, repository and viewing direction. README leads
    with the product render; trl stays 3.
    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
2026-10-01 Image quality pass: legible exploded views, flow diagrams and drawing sheets
    Kit 1.6.1 image layout: the parts list sits in its own column, number bubbles sit on visible parts and never overlap, small parts get a leader, pictures are cropped to the subject, flow labels keep numbers with their units, and sheet captions and the revision table no longer overprint. Concept images, blueprint and general arrangement sheet regenerated; repo-specific labels moved clear of other text and lines.
2026-10-01 Kit 1.7.0: constructable design, illustrated build plan and design decisions register
    The design is now constructable: every part can be made and fits its neighbours, with each change recorded in a Design for construction decision record (made under Amish's 2026-09-30 instruction; ope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
    [bom.csv, coolshade-assembly.step, coolshade-assembly.stl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]
2026-10-01 Budget treated as a value-engineering target
    Amish, 2026-10-01: the budget is a hypothetical control target that keeps the design on a value-engineering lens, not a spending limit. Documents now state the value-engineering target and the estima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
2026-10-02 Record Amish's approval of the open-decision recommendations
    Amish approved the recommendation on every open decision in the design decisions register ("i approve your recommendations for all 555 open decisions.", 2026-10-02). Each decision is moved to Decisio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
2026-10-03 Carry approved follow-ups into the design and redo photoreal renders
    Amish approved the follow-up actions from the open-decision sign-off ("APPROVED CHANGES, COMPLETE THESE", 2026-10-02), the design-for-construction change tables in ten repos, the last wave's open dec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

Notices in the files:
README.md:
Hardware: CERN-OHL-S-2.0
